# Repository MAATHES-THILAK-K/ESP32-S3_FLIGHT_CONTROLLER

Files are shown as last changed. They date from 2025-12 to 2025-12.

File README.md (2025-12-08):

# ESP32-S3 Flight Controller Board
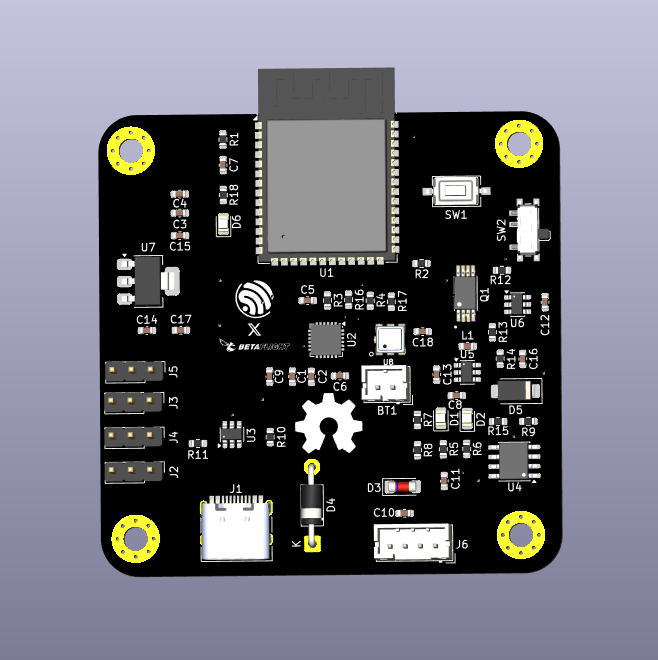
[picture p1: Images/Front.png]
Board Render


A custom-designed flight controller based on the ESP32-S3 module, built for compatibility with the **esp-fc** firmware and **Betaflight-like** configuration.  
This board integrates essential flight-control sensors, power-management circuitry, and expansion interfaces, making it suitable for quadcopters, robotics, and experimental UAV platforms.

---

## 📌 Key Features

### **Core MCU**
- ESP32-S3 bare module
- Dual-core Xtensa LX7 processor
- Native USB for firmware flashing

### **Integrated Sensors**
- **MPU6050** – 6-axis gyro + accelerometer  
- **BMP180** – Barometric pressure & altitude sensor

### **Power System**
- **TP4056** Li-ion charging module with protection  
- **Boost converter (4.2 V → 5 V)** for stable ESP32-S3 power  
- On-board 3.3 V regulator

### **Motor & IO Support**
- **4-Motor outputs** (quad-rotor configuration)  
- Dedicated timer pins compatible with `esp-fc` firmware  
- JST-I2C connector for user-defined expansion modules

### **Firmware Compatibility**
- Fully compatible with  
  - https://github.com/rtlopez/esp-fc  
  - Betaflight-style configuration  
- Designed around the esp-fc recommended pin mappings

---

## 📂 Repository Structure

```

ESP32-FC-Board/
│
├── README.md              # Project documentation
├── LICENSE                # Apache license recommended
├── Hardware/
|___Gerber/                # Gerber files for PCB manufacturing
├── 3DModels/              # STEP/WRL models (optional)
└── Images/                # Photos, renders, pinout diagrams

```

---

## 🛠️ Hardware Overview

### **Sensors**
- MPU6050 connected via I2C  
- BMP180 connected via I2C  
- Pull-ups included where required  

### **Power Path**
- USB or battery input  
- Charging through TP4056  
- Protected 4.2 V → boosted 5 V  
- Local 3.3 V regulator for ESP32-S3 & sensors

### **Connectors**
- Motor outputs (4x)
- I2C JST connector for add-on modules
- Debug pads (TX/RX/5V/GND)

---

## 🚀 Firmware Setup

1. Clone the `esp-fc` firmware:  
```

[https://github.com/rtlopez/esp-fc](https://github.com/rtlopez/esp-fc)

```

2. Select **ESP32-S3 target** in configuration.

3. Flash firmware using:  
- Betaflight Configurator

4. Configure sensor orientation and motor mapping as per schematics.

---

## 📄 Manufacturing

The `Hardware/Gerber/` folder includes:
- Top/Bottom Copper  
- Solder mask  
- Silkscreen  
- Drill files  
- Board outline  

These files can be uploaded to any PCB manufacturer such as JLCPCB, PCBWay, or OSH Park.

---

## 📸 Images & Diagrams

Board renders, real PCB photos, and pin-mapping diagrams are available in:

[Images](Images)

---

## 📜 License

This project is open-source.  
Choose your preferred license (MIT recommended for hardware projects).

---

## 🙌 Contributions

Contributions, improvements, and documentation updates are welcome.  
Feel free to open issues or pull requests.

---

## 📧 Contact

For questions, improvements, or collaboration ideas, open an Issue or contact the project maintainer.

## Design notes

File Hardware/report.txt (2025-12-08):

Plotted to '/home/kmt-universe/Desktop/ESP32_FC.pdf'.

Info: Done.
Info: Done.

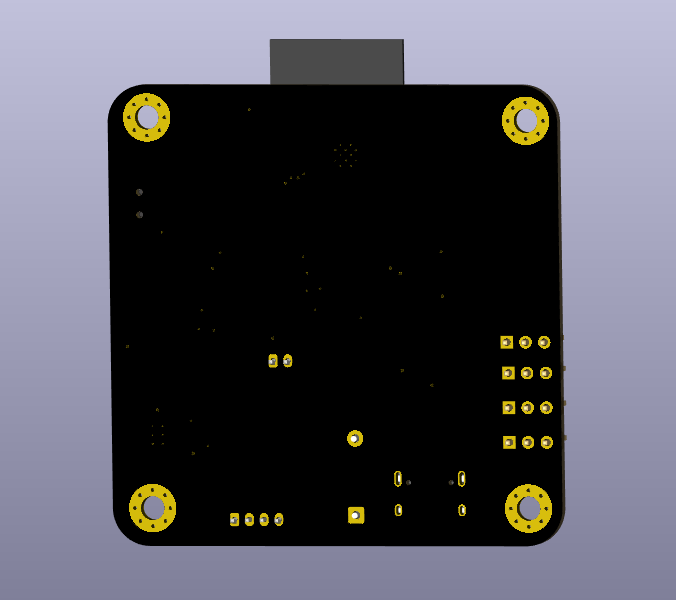
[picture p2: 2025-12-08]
Images/Back.png

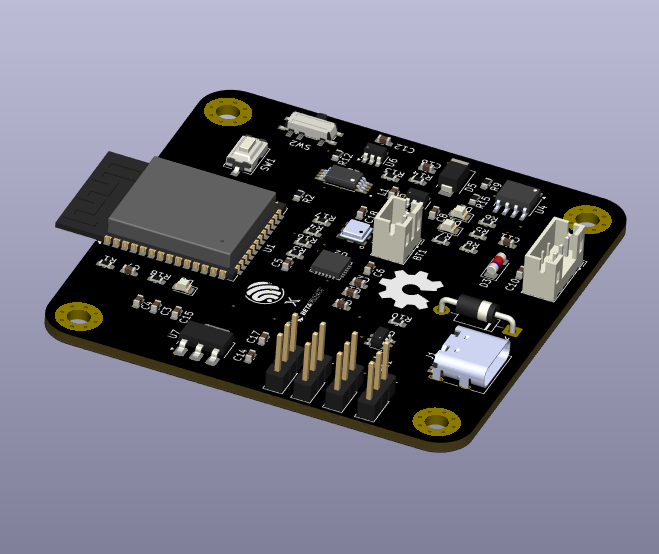
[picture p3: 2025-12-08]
Images/Isometric.png

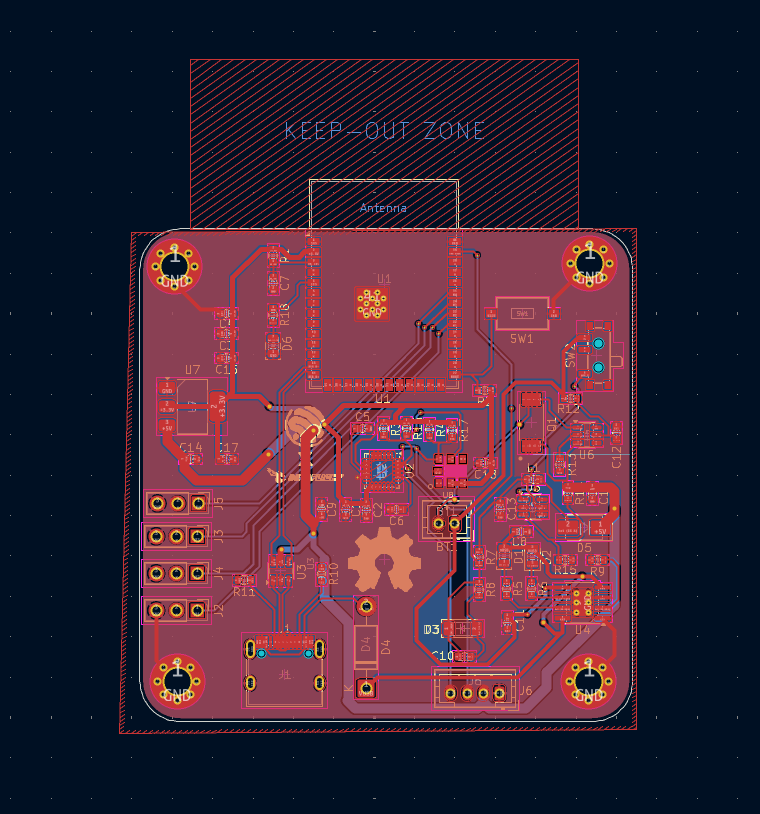
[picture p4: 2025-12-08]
Images/Layout.png

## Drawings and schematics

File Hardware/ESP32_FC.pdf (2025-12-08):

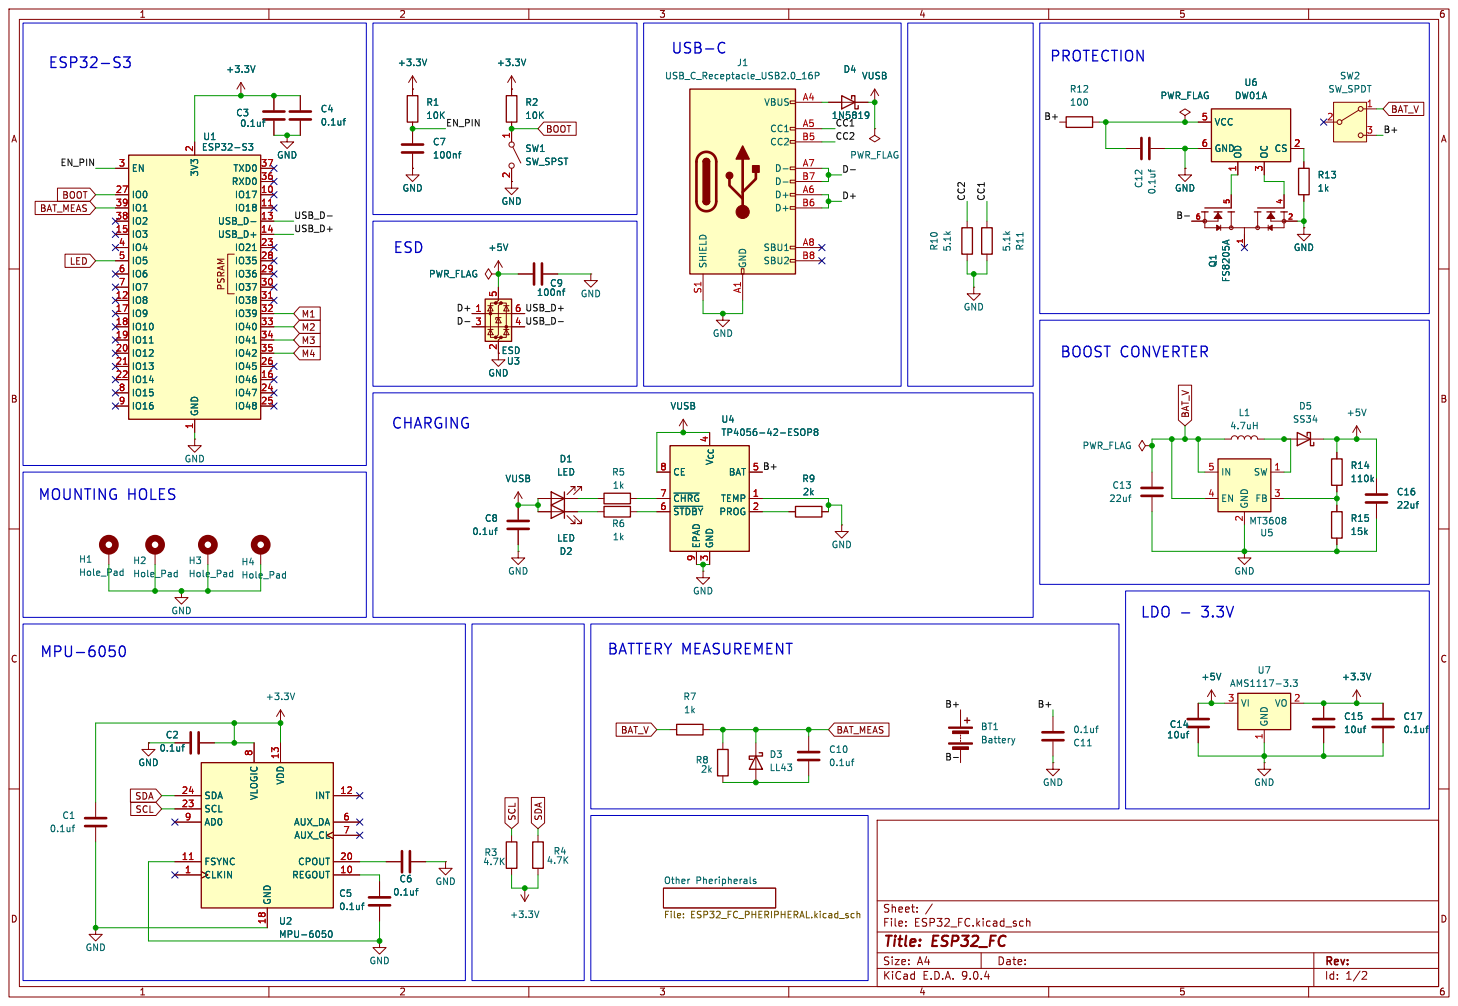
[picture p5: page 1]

3 BAT 5 TEMP 1 PROG 2 U4 TP4056-42-ESOP8 GND SHIELD S1 GND A1 VBUS A4 CC1 A5 CC2 B5 D- A7 D- B7 D+ A6 D+ B6 SBU1 A8 SBU2 B8

File: ESP32_FC.kicad_sch Sheet: / Other Pheripherals File: ESP32_FC_PHERIPHERAL.kicad_sch

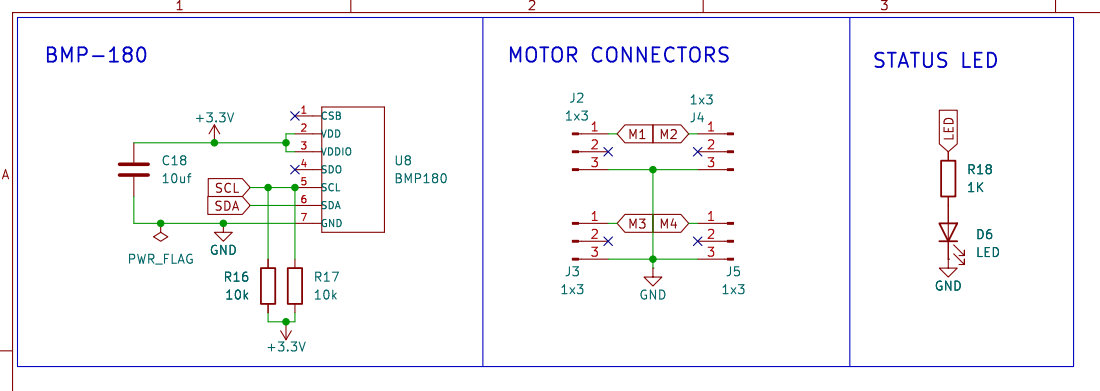
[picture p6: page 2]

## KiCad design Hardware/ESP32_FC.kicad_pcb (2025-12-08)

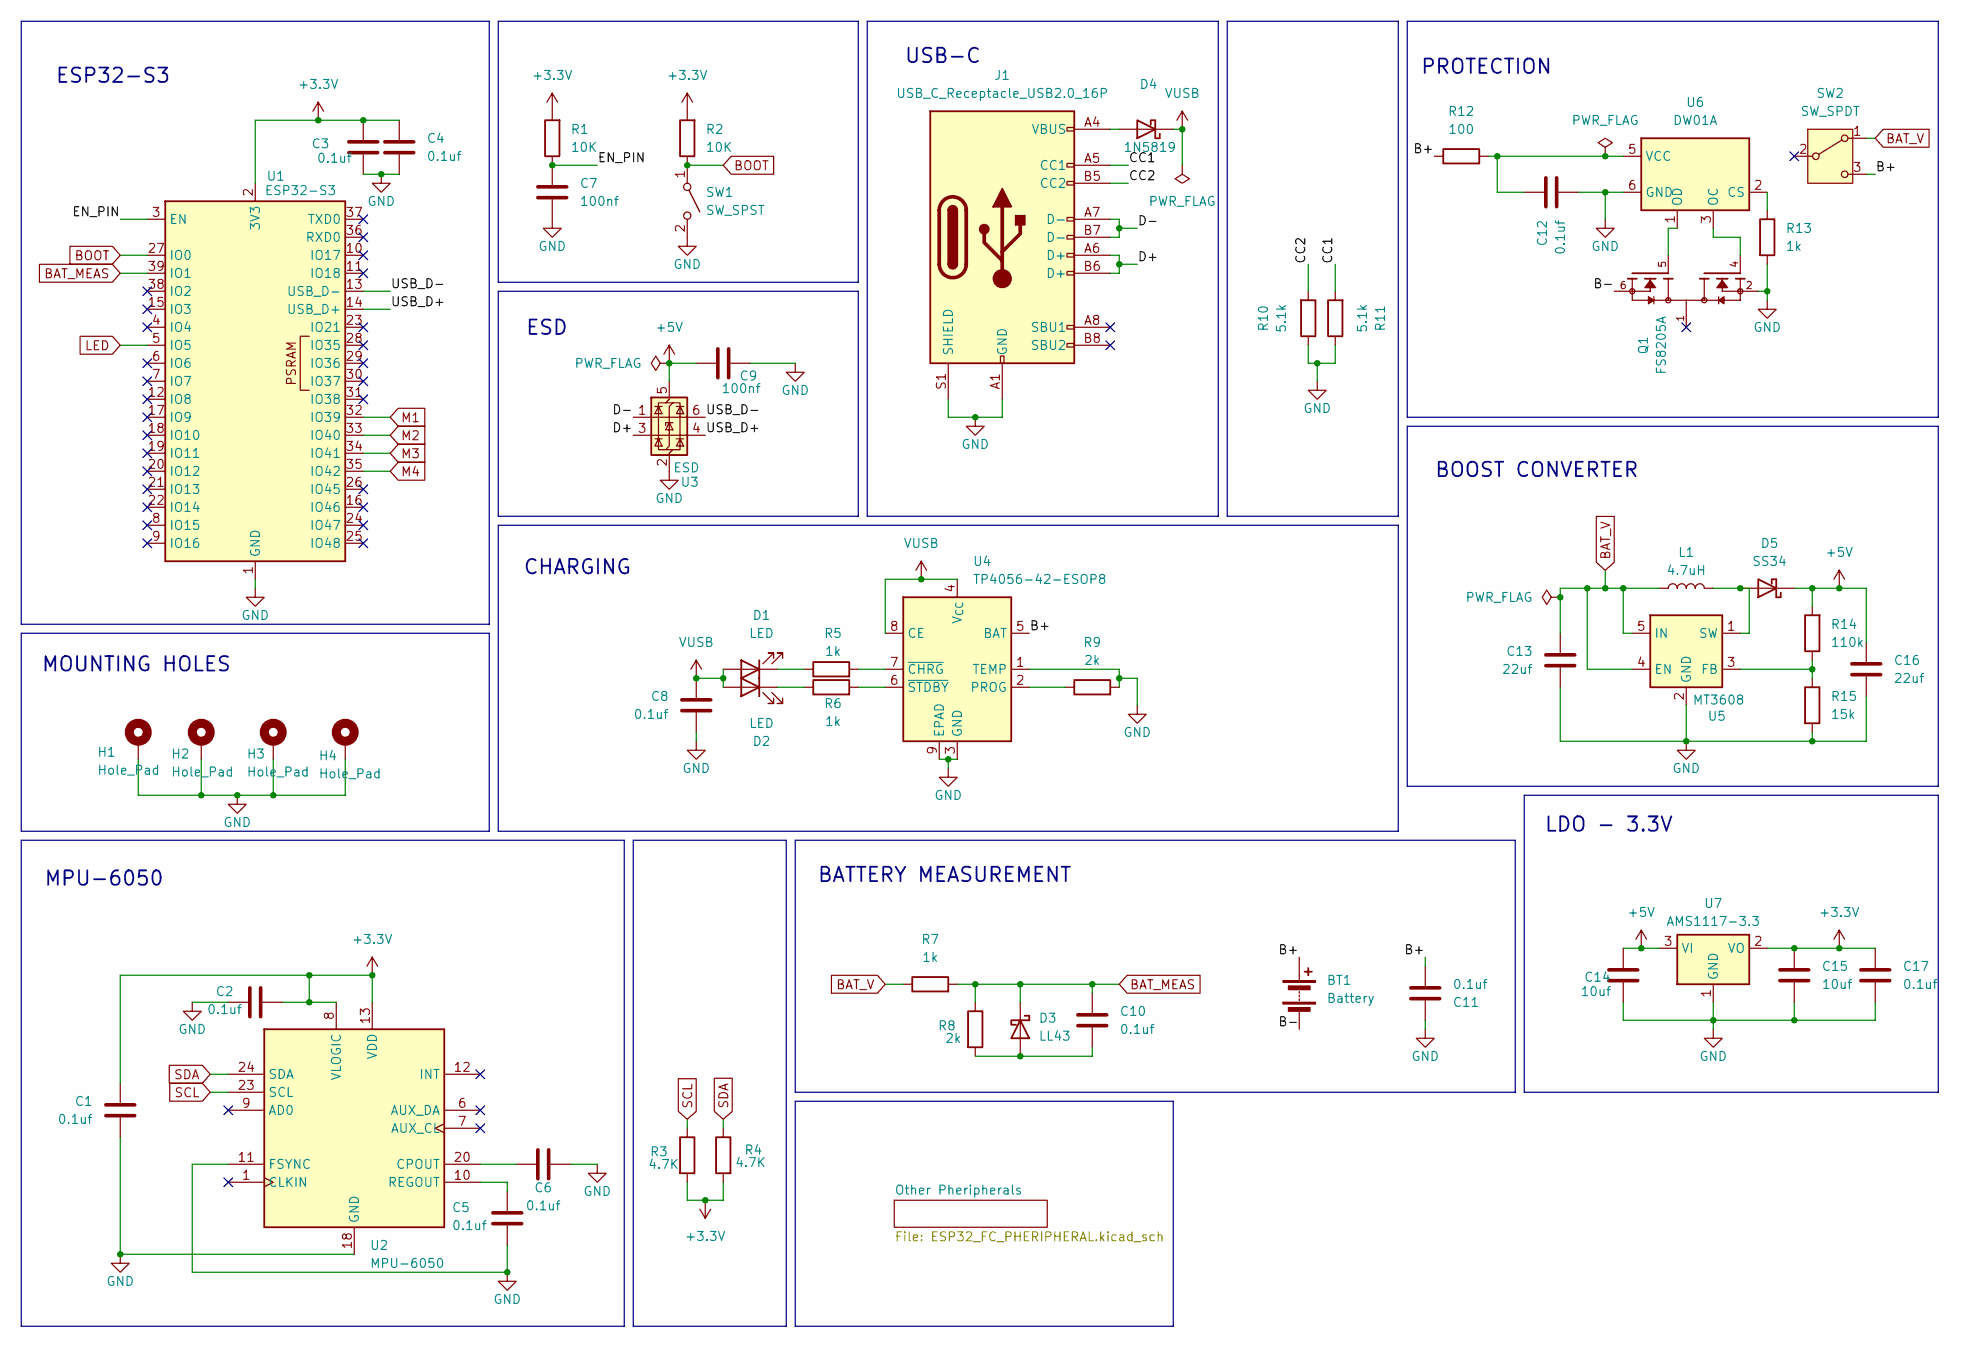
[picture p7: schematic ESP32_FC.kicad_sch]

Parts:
BT1: Battery; JST_PH_B2B-PH-K_1x02_P2.00mm_Vertical
C1, C2, C3, C4, C5, C6, C8, C10, C11, C12, C17: 0.1uf; C_0603_1608Metric
C7, C9: 100nf; C_0603_1608Metric
C13, C16: 22uf; C_0603_1608Metric
C14, C15: 10uf; C_0603_1608Metric
D1, D2: LED; LED_0805_2012Metric
D3: LL43; D_MiniMELF
D4: 1N5819; D_DO-41_SOD81_P10.16mm_Horizontal
D5: SS34; D_SMA
H1, H2, H3, H4: Hole_Pad; MountingHole_3.2mm_M3_Pad_Via
J1: USB_C_Receptacle_USB2.0_16P; USB_C_Receptacle_HRO_TYPE-C-31-M-12
L1: 4.7uH; C_0603_1608Metric
Q1: FS8205A; SOP65P640X120-8N; PARTREV 1.7
R1, R2: 10K; R_0603_1608Metric
R3, R4: 4.7K; R_0603_1608Metric
R5, R6, R7, R13: 1k; R_0603_1608Metric
R8, R9: 2k; R_0603_1608Metric
R10, R11: 5.1k; R_0603_1608Metric
R12: 100; R_0603_1608Metric
R14: 110k; R_0603_1608Metric
R15: 15k; R_0603_1608Metric
SW1: SW_SPST; SW_Tactile_SPST_NO_Straight_CK_PTS636Sx25SMTRLFS
SW2: SW_SPDT; SW_SPDT_PCM12
U1: ESP32-S3; ESP32-S3-WROOM-1
U2: MPU-6050; InvenSense_QFN-24_4x4mm_P0.5mm
U3: ESD; SOT-23-6
U4: TP4056-42-ESOP8; SOIC-8-1EP_3.9x4.9mm_P1.27mm_EP2.41x3.3mm_ThermalVias
U5: MT3608; SOT-23-6
U6: DW01A; SOT-23-6
U7: AMS1117-3.3; SOT-223-3_TabPin2

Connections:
+3.3V: C1.1, C2.2, C3.1, C4.1, C15.1, C17.1, R1.2, R2.2, R3.2, R4.2, U1.2 (3V3), U2.8 (VLOGIC), U2.13 (VDD), U7.2 (VO); also elsewhere on the board
+5V: C9.1, C14.1, C16.1, D5.1 (K), R14.2, U3.5 (VBUS), U7.3 (VI); also elsewhere on the board
/B+: BT1.1 (+), C11.2, R12.1, SW2.3 (C), U4.5 (BAT)
/B-: BT1.2 (-), Q1.6, Q1.7
/CC1: J1.A5 (CC1), R11.2
/CC2: J1.B5 (CC2), R10.2
/D+: J1.A6 (D+), J1.B6 (D+), U3.3 (I/O2)
/D-: J1.A7 (D-), J1.B7 (D-), U3.1 (I/O1)
/EN_PIN: C7.1, R1.1, U1.3 (EN)
/USB_D+: U1.14 (USB_D+), U3.4 (I/O2)
/USB_D-: U1.13 (USB_D-), U3.6 (I/O1)
BAT_MEAS: C10.1, D3.1 (K), R7.2, R8.1, U1.39 (IO1)
BAT_V: C13.1, L1.1, R7.1, SW2.1 (A), U5.4 (EN), U5.5 (IN)
BOOT: R2.1, SW1.1 (A), U1.27 (IO0)
GND: C1.2, C2.1, C3.2, C4.2, C5.2, C6.2, C7.2, C8.2, C9.2, C11.1, C12.2, C13.2, C14.2, C15.2, C16.2, C17.2, H1.1, H2.1, H3.1, H4.1, J1.A1 (GND), J1.A12 (GND), J1.B1 (GND), J1.B12 (GND), J1.S1 (SHIELD), Q1.2, Q1.3, R9.2, R10.1, R11.1, R13.2, R15.2, SW1.2 (B), U1.1 (GND), U1.40 (GND), U1.41 (GND), U2.11 (FSYNC), U2.18 (GND), U3.2 (GND), U4.1 (TEMP), U4.3 (GND), U4.9 (EPAD), U5.2 (GND), U6.6 (GND), U7.1 (GND); also elsewhere on the board
LED: U1.5 (IO5); also elsewhere on the board
M1: U1.32 (IO39); also elsewhere on the board
M2: U1.33 (IO40); also elsewhere on the board
M3: U1.34 (IO41); also elsewhere on the board
M4: U1.35 (IO42); also elsewhere on the board
unnamed: D1.1 (K), R5.1
unnamed: D2.1 (K), R6.1
unnamed: C10.2, D3.2 (A), R8.2
unnamed: D4.2 (A), J1.A4 (VBUS), J1.A9 (VBUS), J1.B4 (VBUS), J1.B9 (VBUS)
unnamed: D5.2 (A), L1.2, U5.1 (SW)
unnamed: C6.1, U2.20 (CPOUT)
unnamed: C5.1, U2.10 (REGOUT)
unnamed: R9.1, U4.2 (PROG)
unnamed: R5.2, U4.7 (~CHRG)
unnamed: R6.2, U4.6 (~STDBY)
unnamed: R14.1, R15.1, U5.3 (FB)
unnamed: R13.1, U6.2 (CS)
unnamed: Q1.4, U6.3 (OC)
unnamed: Q1.5, U6.1 (OD)
unnamed: C12.1, R12.2, U6.5 (VCC)
SCL: R3.1, U2.23 (SCL); also elsewhere on the board
SDA: R4.1, U2.24 (SDA); also elsewhere on the board
VUSB: C8.1, D1.2 (A), D2.2 (A), D4.1 (K), U4.4 (V_{CC}), U4.8 (CE)

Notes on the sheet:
PROTECTION
CHARGING
ESP32-S3
BOOST CONVERTER
ESD
MOUNTING HOLES
BATTERY MEASUREMENT
USB-C
LDO - 3.3V
MPU-6050

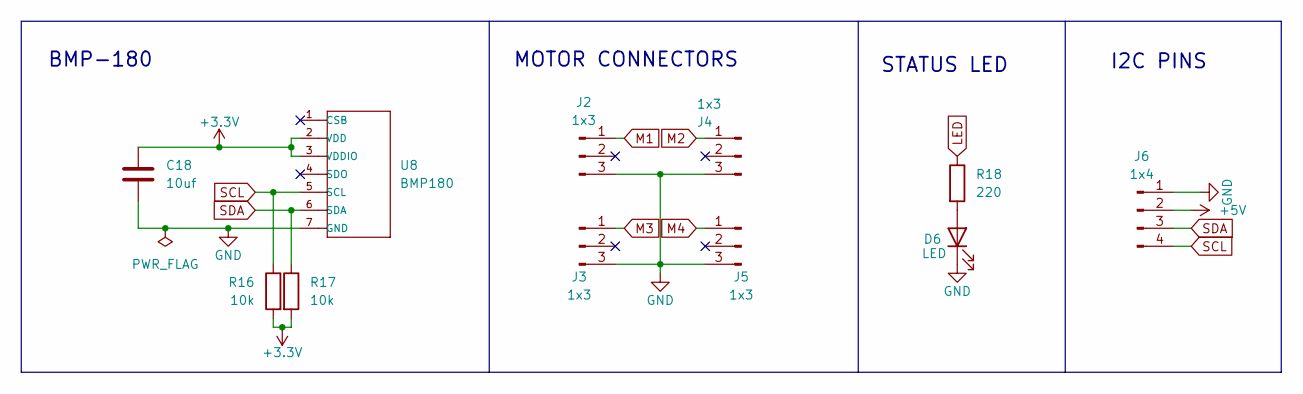
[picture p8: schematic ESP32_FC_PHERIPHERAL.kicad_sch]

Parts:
C18: 10uf; C_0603_1608Metric
D6: LED; LED_0805_2012Metric
J2, J3, J4, J5: 1x3; PinHeader_1x03_P2.54mm_Vertical
J6: 1x4; JST_PH_B4B-PH-K_1x04_P2.00mm_Vertical
R16, R17: 10k; R_0603_1608Metric
R18: 220; R_0603_1608Metric
U8: BMP180; LGA7-1.5-3.8X3.6MM; MPN BMP18

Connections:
+3.3V: C18.1, R16.2, R17.2, U8.2 (VDD), U8.3 (VDDIO); also elsewhere on the board
+5V: J6.2; also elsewhere on the board
GND: C18.2, D6.1 (K), J2.3, J3.3, J4.3, J5.3, J6.1, U8.7 (GND); also elsewhere on the board
LED: R18.1; also elsewhere on the board
M1: J2.1; also elsewhere on the board
M2: J4.1; also elsewhere on the board
M3: J3.1; also elsewhere on the board
M4: J5.1; also elsewhere on the board
unnamed: D6.2 (A), R18.2
SCL: J6.4, R16.1, U8.5 (SCL); also elsewhere on the board
SDA: J6.3, R17.1, U8.6 (SDA); also elsewhere on the board

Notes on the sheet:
MOTOR CONNECTORS
I2C PINS
BMP-180
STATUS LED

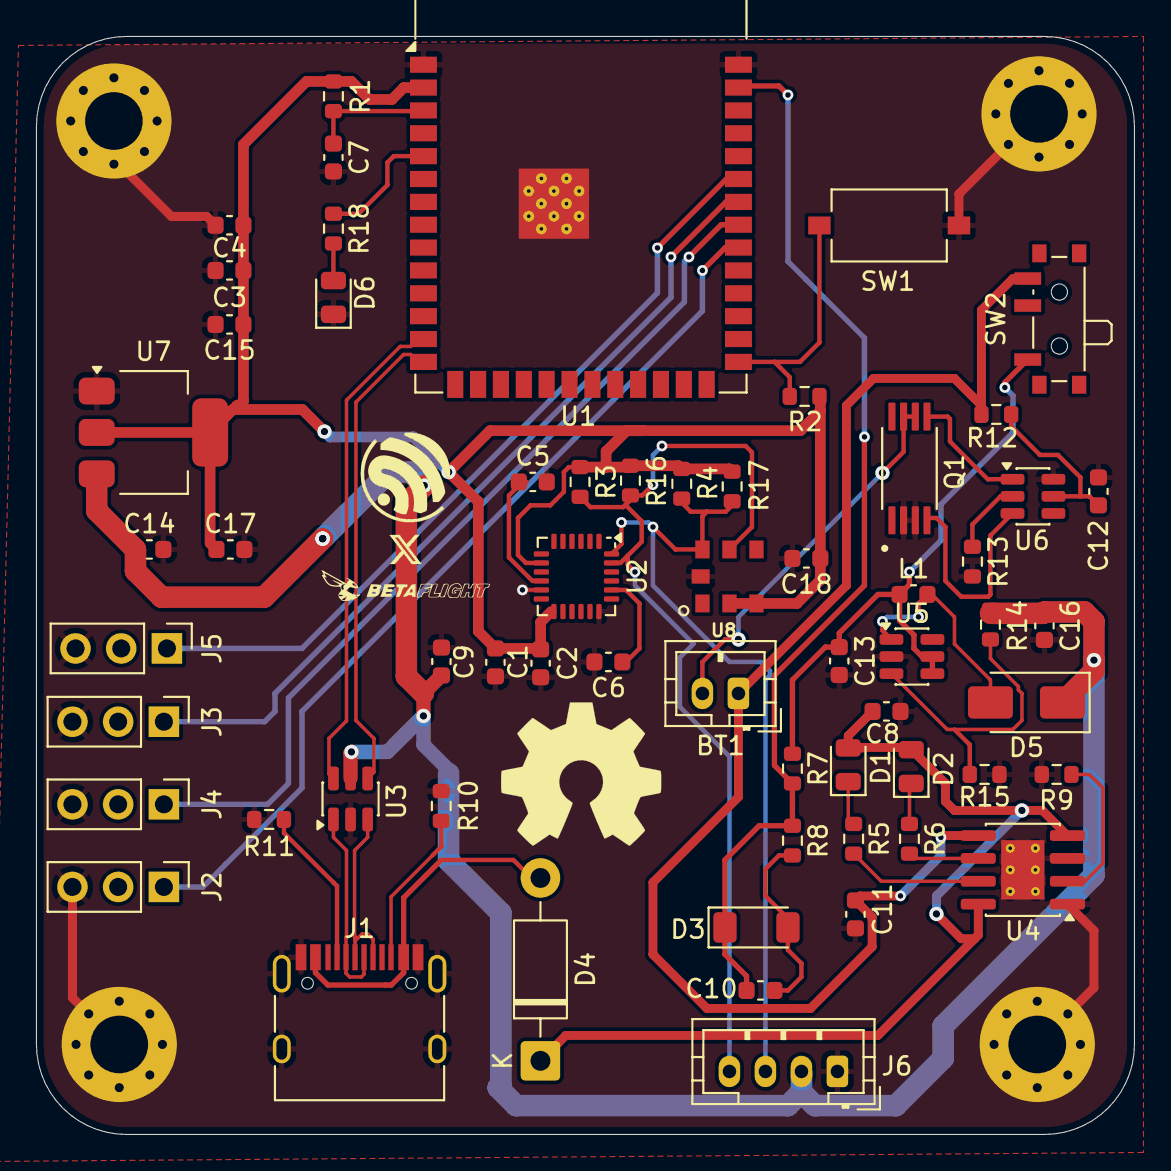
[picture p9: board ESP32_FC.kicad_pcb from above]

Board: 2 copper layers, 61.0 x 61.0 mm, 65 parts (0 on the bottom side), 39 nets.
